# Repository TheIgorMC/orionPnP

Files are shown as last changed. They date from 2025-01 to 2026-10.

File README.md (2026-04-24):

# OrionPnP

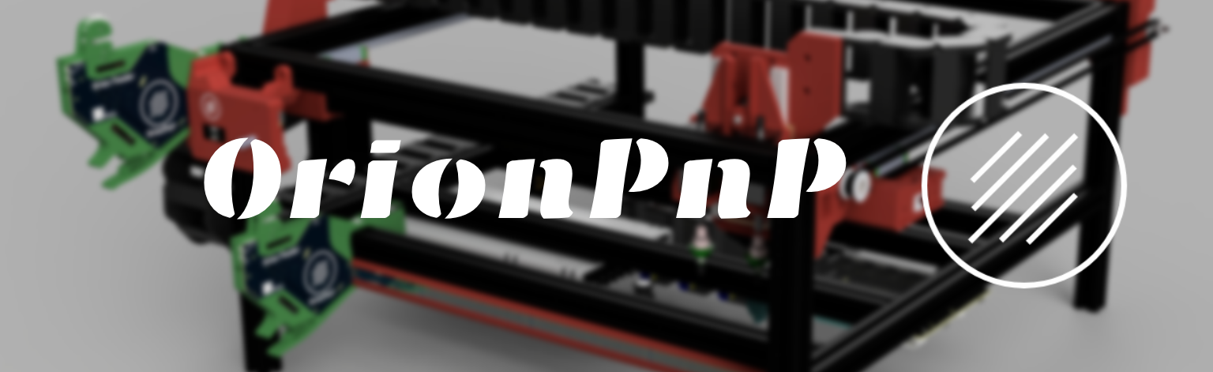
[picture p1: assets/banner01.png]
Banner for OrionPnP


> ⚠️ **DISCLAIMER:** OrionPnP is a prototype under active development. Testing and validation will begin after the first boards are fully assembled. Schematic, PCB, and BOM details may still change. Refer to the [Changelog](../../wiki/Changelog) and [Build Your Own](../../wiki/Build-Your-Own) pages for updates.

---

## What is OrionPnP?

**OrionPnP** is an open-source DIY Pick-and-Place (PnP) machine designed to integrate seamlessly with [OpenPnP](http://openpnp.org).  
The goal is to reliably place at least **0402 components**, while minimizing complexity and user effort — affordably and efficiently.

---

## Why This Project?

Most DIY PnP machines today are either:
- Too expensive
- Too unreliable
- Or both

**OrionPnP** takes a different path: _“minimum effort for maximum reliability.”_  
This means fewer parts, cleaner electronics, and a streamlined build process — optimized for consistent, precise assembly.

As of now, a complete OrionPnP machine (including electronics, mechanics, and **five assembled feeders**) is expected to cost around **800 EUR**, excluding printed parts. This makes it one of the most affordable fully-featured PnP options available.

---

## Why a Custom Mainboard?

Generic motion control boards (like 3D printer boards):
- Often include features irrelevant to PnP (e.g., CAN, multiple extruder support)
- Lack native support for vacuum sensing or multiple solenoids
- Are either too limited, too bloated, or too expensive

**OrionPnP introduces a purpose-built controller**:  
Just the features a PnP machine needs — nothing more.

---

## Key Features

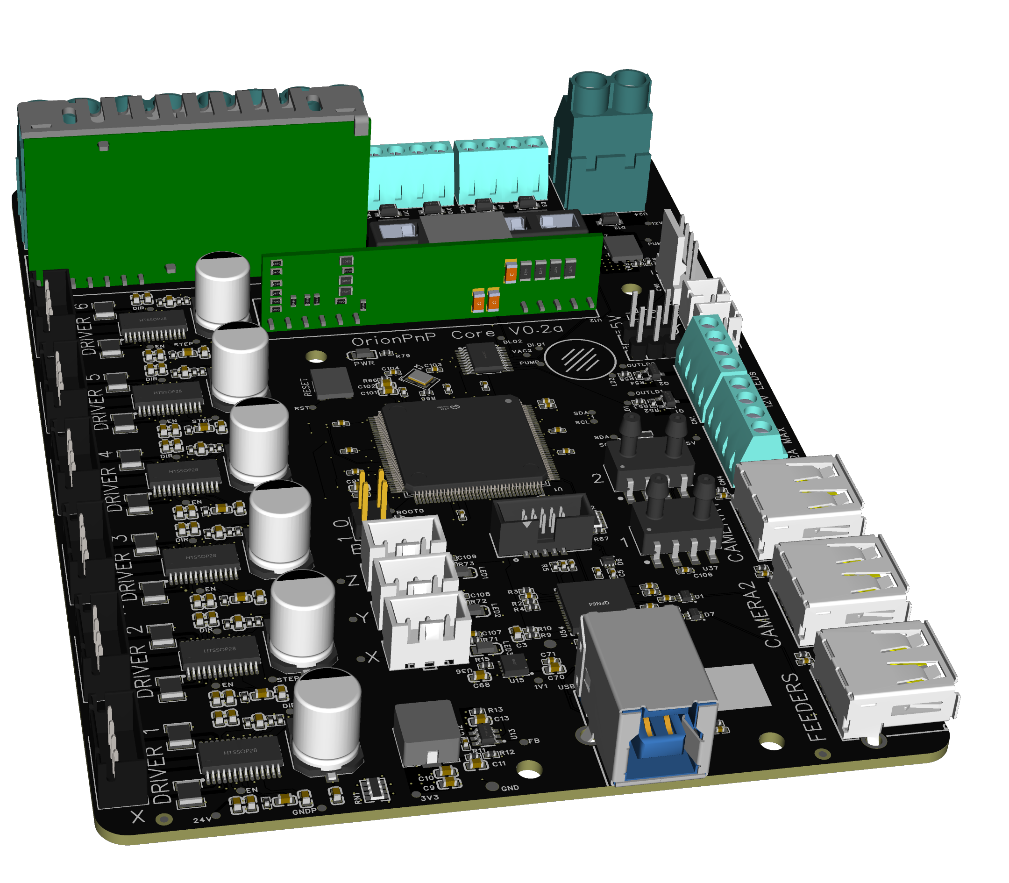
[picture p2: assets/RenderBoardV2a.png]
Render of the mainboard


### Motion & Control
- 6x **TMC2226 stepper drivers** with sensorless homing and UART control
- 4x **12V solenoid outputs** (flyback diodes pre-installed)
- 2x **12V LED ring outputs** for bottom and nozzle cameras
- 1x **12V vacuum pump output**, with back EMF protection

### Power & Expandability
- 24V input, 12V and 5V power rails with onboard buck converters
- 2x **2-pin fan headers** (selectable 5V or 12V)
- 1x **4-pin PC fan header** (12V only, non-PWM)
- Automotive-style fuses for 5V and 12V outputs

### Sensing
- 2x **I²C differential pressure sensors** (one per nozzle)
- Each sensor is isolated on its own I²C bus

### USB & Connectivity
- Integrated **USB 3.0 hub**
  - 3x downstream USB 2.0 ports
  - 1x direct stream to the MCU
  - USB 3.0 Type-B upstream port
  - One port is reserved for a **feeder expansion board**

---

## Software Approach

The mainboard runs a **customized Marlin 2.0 build**, chosen for:
- Mature GCODE support
- Existing OpenPnP compatibility
- Flexibility and ease of expansion

Current modifications include:
- Vacuum sensor hooks
- Solenoid and pump control
- LED and GPIO support for pick-and-place automation

More firmware integration details are covered in the [Software Overview](../../wiki/Software-Overview).

---

## Modular Feeder System

OrionPnP includes a distributed architecture of **smart feeders**, connected via RS485.  
Each feeder has its own microcontroller, optical sensors, and a command queue system.  
Feeders are assigned addresses automatically and can be hot-plugged or programmed via a dedicated interface.

See [Feeder Design](../../wiki/Feeder-Design) and [Command Reference](../../wiki/OrionProtocol) for full details.

---

## Host Interface

A **host controller** can manage feeders independently of the mainboard.  
It supports:
- Multi-line RS485 management
- Address assignment via screen + encoder
- OLED feedback and status display
- USB communication to OpenPnP

Typically based on the **STM32F072**, as described in the [Software Overview](../../wiki/Software-Overview).

---

## Tool Board

A dedicated **ToolBoard** (V0.1a) is mounted on the machine head and handles nozzle-level functions:
- Interfaces with solenoids, sensors, and LED lighting local to the toolhead
- Designed to reduce wiring runs back to the mainboard
- Hardware files (schematic, PCB, BOM, Gerbers, PnP CSV) are available in the [`ToolBoard/`](ToolBoard/) directory

---

## Reflow Oven

OrionPnP includes a companion **Reflow Oven** system for completing the board assembly workflow, built around a consumer oven (De'Longhi 3835A) to avoid expensive commercial controllers.

The system is developed in two phases:

### Phase 1 — Non-invasive monitoring (current)
- **RP2040 Pico firmware** (MicroPython): reads a MAX31855K SPI thermocouple amplifier every 500 ms and streams JSON lines over USB CDC serial
- **PC desktop application** (Dear PyGui, Python 3): connects to the Pico by USB VID/PID auto-detection, displays a live temperature graph, logs data to timestamped CSV, and runs a **"Follow Me"** guided reflow mode
- A **hardware-free MCU simulator** (`tools/simulate_mcu.py`) lets you develop and test the app without physical hardware, via virtual COM ports
- Targets low-temperature pastes (e.g. Sn42Bi58, ~138 °C peak)

### Phase 2 — Full hardware mod (future)
- Adds SSR control for closed-loop automated reflow (PC-bound PID or standalone Pico-resident PID)
- Supports standard and lead-free paste profiles (up to ~250 °C)

See [`Reflow-Oven/`](Reflow-Oven/) for firmware, app source, and the full phase specification.

---

## Assembly Manuals

Preliminary assembly manuals (PDF) for the first revision of the machine are available in the repo root:
- [Manual R01 V01a](Manual_R01_V01a.pdf)
- [Manual R01 V01b](Manual_R01_V01b.pdf)
- [Manual R01 V01c](Manual_R01_V01c.pdf)
- [Manual R01 V01d](Manual_R01_V01d.pdf) _(latest)_

---

## Project Scope

The core mainboard is in active prototyping.  
Feeder electronics and mechanics are now being finalized.  
CAD files, firmware, schematics, and wiring diagrams will all be published under open-source licenses.

See [Build Your Own](../../wiki/Build-Your-Own) for parts list, tools, and assembly tips.

---

## Project Status

- [x] CAD design of the frame and motion system
- [x] Production of electronic boards (Core, camera lights, toolhead boards...)
- [x] Assembly manual — first revision published (R01 V01d)
- [ ] First tests on electronics (ongoing...)
- [ ] Part printing (ongoing...)
- [x] Reflow oven Phase 1 app and firmware (in progress)

---

## Contributions Welcome

OrionPnP is a community-first project.  
Feel free to:
- Fork the repo
- Suggest improvements
- Report bugs or build issues

Please check in before large architectural changes — development is moving fast.

---

Stay tuned for updates on feeder programming, mechanical parts, and full assembly instructions.

---

## Support the Project

If you find OrionPnP useful or want to support its continued development, consider buying me a coffee:



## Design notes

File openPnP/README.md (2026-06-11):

# openPnP Configuration

This folder contains the openPnP configuration and supporting files for the Orion PnP machine.

## Files

| File | Description |
|---|---|
| `machine.xml` | Main openPnP machine configuration (axes, drivers, cameras, nozzles, feeders) |
| `packages.xml` | Component package definitions (footprints) |
| `parts.xml` | Parts library with component-to-package mappings |
| `vision-settings.xml` | Vision pipeline settings for part and fiducial detection |

## Scripts

Example scripts are provided in `scripts/Examples/` in both JavaScript and Python.

### JavaScript (`scripts/Examples/JavaScript/`)
- `Hello_World.js` — Basic scripting example
- `Move_Machine.js` — Machine movement control
- `Pipeline.js` — Vision pipeline scripting
- `Reset_Strip_Feeders.js` — Reset all strip feeders
- `QrCodeXout.js` — QR code utility
- `Call_Java.js` — Calling Java methods from scripts
- `Print_Scripting_Info.js` — Print available scripting objects
- `Utility.js` — General utility functions

### Python (`scripts/Examples/Python/`)
- `move_machine.py` — Machine movement control
- `print_nozzle_info.py` — Print nozzle status/info
- `print_hallo_openpnp.py` — Basic scripting example
- `call_java.py` — Calling Java methods from scripts
- `print_methods_vars.py` — Inspect available methods and variables
- `print_scripting_info.py` — Print available scripting objects
- `use_module.py` — Example of importing Python modules
- `utility.py` — General utility functions

The `scripts/Events/` folder is reserved for event-triggered scripts (e.g., job start/stop hooks).

### Utilities (`scripts/util/`)

| File | Description |
|---|---|
| `datasheet_to_feeder.py` | Reads a component datasheet PDF via the Gemini API and outputs an openPnP `BlindsFeeder` XML snippet with the extracted tape specs |
| `batch_parts_to_feeders.py` | Reads a CSV list of parts, groups by footprint then variation series, uses Gemini with web search to estimate tape specs and component size, and outputs bulk feeder XML + review report |
| `requirements.txt` | Python dependencies for the util scripts |
| `.env.example` | Template for the required `GEMINI_API_KEY` environment variable |

#### `datasheet_to_feeder.py` usage

```bash
# Install dependencies
pip install -r scripts/util/requirements.txt

# Copy and fill in your Gemini API key
cp scripts/util/.env.example .env

# Run against a datasheet PDF
python scripts/util/datasheet_to_feeder.py path/to/component.pdf \
    --part-id "C_0402_100NF" \
    --name "Feeder_0402_100nF" \
    --output feeder_0402.xml
```

The script uploads the PDF to the Gemini Files API, extracts the following fields, and writes a ready-to-import `<feeder>` XML element:

| Field extracted | openPnP attribute |
|---|---|
| Tape width | `tape-center-offset-mm` (via IEC 60286-3 lookup) |
| Feed pitch (A dimension) | `pocket-pitch` |
| Pocket size (A0/B0) | `pocket-size` |
| Sprocket pitch | `sprocket-pitch` |

The output XML can be pasted directly inside the `<feeders>` section of `machine.xml`.

#### `batch_parts_to_feeders.py` usage (CSV automation)

Use this when you already have a CSV with many part numbers (e.g. `scripts/util/exported.csv`).

```bash
# Install dependencies
pip install -r scripts/util/requirements.txt

# Run batch generation from a CSV export
python scripts/util/batch_parts_to_feeders.py scripts/util/exported.csv \
    --output scripts/util/feeders_generated.xml \
    --report scripts/util/feeders_generated_report.csv
```

What it does:

1. Reads `id`, `manufacturer_code`, and `smd_footprint` from the CSV.
2. Groups parts by `smd_footprint` first, then by inferred series/variation.
3. Calls search-enabled Gemini (`gemini-2.5-flash` + Google Search tool) per variation group to infer tape specs and component size.
4. Generates one `<feeder>` per CSV row with the inferred variation specs.
5. Writes a review CSV with footprint, variation, confidence, component dimensions, and datasheet URL.

The XML output contains a `<feeders>` root with comments showing footprint, variation, confidence, dimensions, and a datasheet source link for each block.

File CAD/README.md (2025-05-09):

# OrionPnP CAD & 3D Models

> This directory contains mechanical design files and 3D models used in the OrionPnP project. These are actively maintained and subject to change as hardware validation continues.

---

## Overview

The OrionPnP mechanical design is built around modularity and printability. It includes mounts, brackets, covers, and pogo-compatible parts used in the feeder system and frame.

The CAD models are designed with:
- **Fusion 360** as the main parametric environment
- STL exports for printing (3MF is gradually being added)
- A BOM covering all fasteners and support components, alongside the list of 3D printed components

---

## Contents

| File/Folder | Description |
|---|---|
| `/Feeders/` | Exported 3D files for feeders (M3F + STL) |
| `/OrionPnP/` | Exported 3D files for the machine (STL) |
| `OrionPnP_Main.f3d`| Main Fusion 360 assembly file (WIP) |
| `Hardware BOM.ods` | BOM spreadsheet (for components and 3D printed parts) |
| `TEMP_BOM.md` | Temporary Markdown file for quick BOM consultation |

---

## Notes

- Printed parts **should** be printable with smaller printers (e.g. Prusa Mini)
- STL exports are named by part function for easier identification
- Most parts are designed for **0.6mm nozzle, 0.2mm layer height**

---

## Bill of Materials

The [TEMP_BOM.md](./TEMP_BOM.md) file contains a full breakdown of:
- Printed parts
- Hardware (screws, nuts, spacers, etc.)
- Optional assembly tools and adhesives

---

## Printing Recommendations

- Material: **ABS/ASA** or **PETG** recommended for most parts
- Color: not relevant except for camera mounts (preferable black + white diffuser)
- Infill: 30–50% for structural components
- Supports: Only required for a few overhangs (noted per part)
- Use heat-set inserts for repeated fastening when indicated

---

## License

All CAD files are released under the same open-source license as the rest of the project. You are free to modify and redistribute them, but attribution is appreciated.

---

## Related Pages

- [Build Your Own](../../wiki/Build-Your-Own)
- [Feeder Design](../../wiki/Feeder-Design)
- [Hardware Overview](../../wiki/Hardware-Details)

---

Stay tuned as we finalize the mechanical design and publish full step-by-step assembly guides.

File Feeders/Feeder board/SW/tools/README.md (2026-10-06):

# RS485 command sender

Small PC-side tools for driving the feeder RS485 protocol directly from a
USB-RS485 adapter, instead of only through the debug port's text
commands. See `../PROTOCOL.md` for the frame format and full command
reference these implement against. Two front ends, same protocol logic
(`rs485_protocol.py`, shared by both):

- **`rs485_gui.py`** — Tkinter GUI. No separate install beyond pyserial
  (Tkinter ships with Python). Probably the one to start with.
- **`rs485_sender.py`** — command-line REPL, same commands as the GUI's
  "Custom command" panel, handy for scripting or an SSH session.

## Setup

```
pip install -r requirements.txt
```

## GUI

```
python rs485_gui.py
```

Pick a port and Connect. The baud is pre-filled from the newest firmware
folder's `RS485_BAUD` (read from `../<firmware>/src/main.cpp`); pick a
different firmware in the dropdown if the board runs an older build.
If the adapter needs the host to drive its direction pin manually (some
cheap adapters wire DE to RTS instead of auto-detecting direction), tick
"RTS controls TX (DE)" before connecting.

Every frame that arrives shows up in the log, decoded where the payload
shape is known (the once-a-second live refresh and the config read stay
out of it). Port, address and a few settings are remembered in
`~/.orionpnp_rs485_gui.json`.

**The feeder card** (left, always visible) is the part to watch during
first tests: the target **Address**, Ping / Identify / Refresh, a big red
**STOP** (also **Esc**), and live readouts that refresh once a second while
nothing else is running: link health, magnet (detected / none / too weak /
too strong), motor-driver fault, RS485 relay, wheel angle, 12V current
(approximate, from the factory calibration - the feeder's own `CALI` value
may differ) and the last move error. Below that, **Saved on this feeder**
shows component id, tape zero, pitch, tape width, peel time and peel rate,
read automatically the first time the feeder answers (and with **Read from
feeder**). Fields show "n/a" on firmware that doesn't have them. **STOP**
aborts the running sequence and broadcasts `CMD_STOP`; a feeder only hears
it between moves, because it does not listen to the bus while a motor runs.
The Identify button blinks the feeder's status LED white. v0.02b feeders
also flash their status LED green (blue in peel mode) whenever a frame is
addressed to them, so you can see which one is answering.

Tabs:

- **Bring-up.** A first-test checklist: connect, address, link, magnet and
  fault, tape width, pitch, zero, feed once, peel rate. Each row has its
  own button. Ticks come from what the feeder reports, so a feeder that
  was set up earlier shows up already done, and a red cross says why.
- **Feed & peel.** Pitch, Feed once and Back once (with a peel rate saved
  the peel follows, see below); and **Run cycle test**: N cycles of
  feed / peel in the order you pick, waiting for each ACK and logging how
  long each step took, with min/avg/max at the end. With a peel rate saved
  a feed already peels, so use "feed only" (the GUI warns if a cycle would
  peel twice). On v0.02 and earlier the host-side feed-then-peel cycle is
  the only way to pair them. Nothing overlaps: the feeder doesn't listen
  to the bus while a motor is running.
- **Peel calibration** (v0.02b). Four blocks. (1) The **peel rate** (ms of
  peel per mm of feed): save, read, turn off, and **-10/-5/-1/+1/+5/+10 %**
  fine-tune buttons that save immediately. (2) **Measure it**: **Feed (no
  peel)** moves the sprocket N mm with jog (which never touches the peel
  motor), **-250 ... +1000 ms** nudges peel until the cover tape is just
  taut, **Record measurement** adds a row (mm, ms, ms/mm); repeat a few
  times, **Use average**. Every nudge starts with a short soft-start ramp,
  so a few long nudges are closer to a real feed than many short ones; the
  measured number is a starting point. (3) **Verify**: **Feed (peel
  follows)**, **Back (peel reverses first)** (`CMD_FEED_BACK`), and N feeds
  in a row; slack after a feed means raise the rate, a pulled tape or a
  lifting pocket means lower it, then use the fine-tune buttons. (4) The
  older fixed-time peel (Peel once, save/read/run the saved time).
- **Jog & zero** (v0.02+). Buttons jog the sprocket by -4 ... +4 mm
  (4 mm = one tooth) or a custom distance, each reply shows the new raw
  angle, then **Set zero here** stores it as the tape zero. Jog does not
  move the peel motor.
- **Setup.** Address: **Scan** lists every unassigned feeder (nonce,
  component, tape width) so you can pick one and **Assign** it, or **Scan +
  assign** does both when exactly one answers and sets the address. Tape
  width (write/read). Status-LED brightness (v0.02b: saved on the feeder,
  presets 10-255). EEPROM: **I2C scan** shows what answers on the feeder's
  bus; if Get serial NACKs but the scan shows 0x50 and no 0x58, the chip is
  a plain AT24C02 with no factory serial: **Random** + **Program serial**
  writes one (read back to verify).
- **Packet builder.** Pick a command and fill in named fields (pitch in
  mm, peel time in ms, dropdowns for direction/motor/on-off). It shows
  what the command does, which reply to expect, gotchas, and a live
  byte-by-byte preview of the exact frame including the CRC. **Copy hex**
  puts the frame on the clipboard for use in another serial terminal. The
  payload hex box can be edited by hand to send something malformed.
  Broadcast-only commands (Discover/Assign) always go to addr 0x00.

## Production (TAP-Jig)

The **Production** tab runs the test-and-program routine for the jig
(pre-power checks, power-up, flash test firmware, switches, RESET, fault
line, LEDs, AS5600, serial number, motors, RS-485, EEPROM, flash production
firmware, final confirm) and logs a pass/fail record per unit. It talks to
the jig's 32u4 over its own USB port and runs avrdude for the ISP stages.
`tapjig_run.py` runs the same routine headless. Everything about it, the
jig line protocol, the test firmware and what is still open, is in
**`TAPJIG.md`**. The jig firmware does not exist yet; `sim_jig.py` stands in
for it.

## Trying it without hardware

`sim_feeder.py` (Linux/macOS only - it uses a pseudo-terminal) behaves
roughly like v0.02b firmware: boots unassigned, answers discovery and the
v0.02/v0.02b commands, and goes deaf while a "motor" runs.

```
python sim_feeder.py [--addr N] [--no-magnet]
```

It prints a device path such as `/dev/pts/5`; type that into the GUI's
Port box (or `rs485_sender.py --port`). It is not a faithful model of the
firmware, only enough to exercise the tools.

## CLI / REPL

```
python rs485_sender.py --list              # see available COM ports
python rs485_sender.py --port COM5         # open an interactive REPL
```

`--baud` defaults to the newest firmware's `RS485_BAUD`, same as the GUI.
If the USB-RS485 adapter needs the host to drive its direction pin
manually, add `--rts-tx` (same situation as the GUI's checkbox above).

Inside the REPL, `help` lists every command. There's a named command for
each protocol command (`ping`, `scan`, `getstatus`, `setpitch`, `peel`,
...) with friendly argument parsing, plus `raw <addr> <cmd> [hexbytes...]`
for sending anything else — custom payloads, malformed frames, whatever
you want to throw at a feeder that the named commands don't cover.

Typical first session on a bus with one feeder:

```
RS485> scan
  broadcasting CMD_DISCOVER, listening for 0.50s...
  RX: addr=0x00 cmd=CMD_DISCOVER_HERE payload=... | nonce=0x1A2B componentId=UNSET tapeWidth=8mm
RS485> assign 0x1A2B 5
  RX: addr=0x05 cmd=CMD_ACK payload=05 | ...
RS485> ping 5
  RX: addr=0x05 cmd=CMD_PONG payload=(empty) |
RS485> getstatus 5
  RX: addr=0x05 cmd=CMD_STATUS_INFO payload=... | angle=12.3deg (raw=140) magnet=OK (MD=1 ML=0 MH=0) fault=0 lastMoveErr=ERR_NONE iMonRaw=0 relay=disconnected
```

Addresses, command codes, and `raw`'s hex bytes all accept either decimal
or `0x..` hex. Bus address `0x00` is broadcast.

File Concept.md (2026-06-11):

### Machine architecture

The **OrionPnP** machine is comprised of:
- The machine itself with:
  - One **mainboard** (ATmega2560 based board) that controls the motors and ligths/pumps/solenoids. Driven via GCODE commands over COM.
  - Two **USB cameras**, one on the picking head, one fixed on the build plate. Each has its own independent USB cable.
  - One **Feeder host**, with at least two RS485 buses. One is for the feeders connected to the machine, one is reserved for a programming slot to program new feeders. Communicates via GCODES over COM.
  - One **feeder rail**, a simple PCB strip to connect feeders to the machine. It carries 12V, GND, A and B from the RS485 bus.
- A computer or SBC with [OpenPnP](https://openpnp.org/) installed and decent processing power.
- Feeders of various types for different tape widths (8, 12, 16...). Each feeder has 2 motors connected to a driver to advance the tape and peel the protective film.

The main concept to understand is that the heavy processing is made on the PC/SBC and the other boards need decresing levels of elaboration done. The hierarchy is like this:

- PC/SBC running OpenPnP
  - Feeder host board
    - Feeders
  - Mainboard of the OrionPnP

The method for adding the feeders to the machine is the one in this procedure:
1. Snap a feeder on the programmer area of the host.
2. Set with the simple menu or via custom PC commands the informations on the carried component (tape width, pitch of parts, part ID). These are used by the feeder to know which parts it is feeding and how to properly drive the motors.
3. Unlatch the feeder from the programmer area of the host.
4. Put the feeder on any empty section of the rail.
5. Some sort of *polling command* runs periodically and detects the new feeder.
6. A time is waited to see if more feeders are connected to either the rail OR the programmer (10s?).
7. After the delay passed, the head moves on the feeder section and a custom script runs on the PC/SBC.

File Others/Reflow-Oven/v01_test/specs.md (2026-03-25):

# Reflow Oven — v01 Test Specification

## Overview

The OrionPnP handles component placement, but a reflow oven is required to complete the board assembly workflow. Commercial solutions are expensive and importing purpose-built controllers (e.g. Controleo3) adds further cost and complexity. The chosen approach is a fully DIY system built around a consumer oven, implemented in two progressive phases.

---

## Hardware Base

| Parameter | Value |
|---|---|
| Oven model | De Longhi 3835A |
| Internal volume | 21 L |
| Rated power | 1800 W |
| Future insulation | Reflective shielding (TBD, Phase 2) |

The 1800 W power rating is acceptable for low-temp pastes. For lead-free profiles with faster ramp rates, additional insulation may be required.

---

## Build Phases

### Phase 1 — Non-invasive monitoring (current focus)

**Goal:** Characterise the oven's thermal behaviour and enable guided manual reflow without any permanent hardware modification.

**Hardware:**
- K-type thermocouple (routed through the oven door seal or a small grommet)
- MAX31855K SPI thermocouple amplifier breakout
- **RP2040 Pico** connected to MAX31855K via SPI

**Firmware:**
- **MicroPython** on the RP2040 Pico
- Samples MAX31855K every 500 ms, streams JSON lines over USB CDC serial
- Output format: `{"t":<uptime_ms>,"tc":<float>,"ref":<float>,"fault":<0|1>}`
- Accepts incoming JSON commands (stubbed for Phase 2 SSR control)

**Software:**
- **Dear PyGui** native desktop application (GPU-rendered, Windows/macOS/Linux)
- Reads temperature over USB serial from the Pico (auto-detects by USB VID/PID 0x2E8A)
- Logs time/temperature data to timestamped CSV
- Implements calibration procedure (see below)
- Implements "Follow Me" guided reflow mode (see below)

**Target paste types:** Low-temperature solder pastes (e.g. Sn42Bi58, ~138 °C peak)

---

### Phase 2 — Full hardware mod (future)

**Goal:** Fully automated reflow with closed-loop control, suitable for standard and lead-free pastes.

Phase 2 supports two independent sub-modes that share the same hardware additions. The UI introduced in Phase 1 remains unchanged; a new **SSR Control** panel is added to the PC app for PC-bound mode.

---

#### Phase 2a — PC-bound mode

The host PC runs the PID control loop. The Pico firmware gains GPIO outputs for SSR1/SSR2 and accepts `{"cmd":"set_ssr","ssr1":0,"ssr2":1}` commands already stubbed in Phase 1 firmware.

- PID executes on the PC; USB round-trip latency (~10–50 ms) is negligible for thermal systems with time constants of tens of seconds.
- The Dear PyGui app gains a **SSR Control** panel: target profile selector, Start/Stop, live PID tuning (Kp/Ki/Kd).
- Logging and calibration workflows from Phase 1 are reused unchanged.

#### Phase 2b — Standalone mode

The PID loop and profile runner move onto the Pico. A display module (hardware TBD) replaces the PC for in-field use.

- Pico firmware extended: profile storage (LittleFS or SD), PID controller, display driver.
- The PC app remains available for monitoring, log download, and profile upload over USB.
- Profile and calibration file formats are identical to Phase 1 (JSON) for full compatibility.

---

**Shared hardware additions (both sub-modes):**
- 2× SSR (Solid State Relay): one for the oven heating elements, one for the convection fan
- At least one additional thermocouple (consider two: air + board surface)
- Replacement thermal fuse rated for cycling use
- Phase 2b only: embedded display module (hardware TBD during Phase 2 design)

**Target paste types:** Lead-free (Sn63Pb37 and SAC305, up to ~250 °C peak)

---

## Phase 1 — Software Specification

### Calibration Procedure

The purpose of calibration is to characterise the oven's thermal response curve — specifically how temperature evolves over time when running at **maximum power**, as a function of the temperature setpoint dialled in.

**Approach:**
- Run the oven at **max power only** (no partial-power sweeps).
- Set several discrete temperature targets across the useful range and record how the measured temperature varies over time for each.
- The script logs the full time/temperature curve for each setpoint, capturing ramp rate, overshoot, and settling behaviour.

**Spatial variation (optional):**
- The procedure can be repeated **2–3 times** with the thermocouple placed in different positions inside the oven cavity (e.g. centre, front corner, near elements) to map thermal uniformity.
- This is particularly relevant for board placement decisions in Follow Me mode.

**Empirical nature:**
- The actual curve shape is unknown until tested on the real oven. The calibration run will drive the design of the Follow Me prediction model — no assumptions are made upfront about linearity or lag characteristics.

**Procedure steps:**
1. Start with oven cold (ambient temperature).
2. Set oven dial to max power.
3. Dial in the first temperature target; script begins logging temperature vs. time.
4. Record until the oven reaches steady state or overshoots and stabilises.
5. Let the oven cool down, then repeat from step 2 for the next temperature target.
6. Optionally repeat the full sequence with the thermocouple repositioned.
7. Script post-processes the logged curves to extract ramp rate (°C/s) and any overshoot per target.

**Output:** A calibration file (JSON or CSV) per thermocouple position, containing the time/temperature curves and derived ramp characteristics, consumed by the Follow Me mode.

---

### Reflow Profiles

A profile defines the target temperature curve for a reflow cycle. Each profile is a sequence of named stages.

**Profile format (example — Sn42Bi58 low-temp paste):**

| Stage | Target temp (°C) | Ramp rate (°C/s) | Dwell time (s) |
|---|---|---|---|
| Preheat | 90 | ~1.0 | 60 |
| Soak | 130 | ~0.5 | 90 |
| Reflow | 165 | ~1.5 | 30 |
| Cooling | ambient | natural | — |

Profiles are stored as simple JSON files so they can be created and edited without modifying the script.

**Fields per stage:**
```json
{
  "name": "Soak",
  "target_temp": 130,
  "max_ramp_rate": 0.5,
  "dwell_seconds": 90
}
```

---

### Follow Me Mode

The script guides the user through a reflow profile by issuing real-time instructions based on live temperature readings and the calibration delta table.

**Behaviour:**
- Displays a live temperature plot (time on X axis, °C on Y axis) with the target profile overlaid.
- Calculates how far ahead of the current temperature the user needs to act (based on the calibration delta) to hit the next stage on time.
- Issues a prompt when the user must change the oven dial setting, including:
  - Which direction to turn (up/down)
  - How many notches/steps (if the dial positions are enumerated during calibration)
- Alerts if the actual temperature curve deviates outside a configurable tolerance band around the target profile.
- Logs the full run (timestamp, setpoint stage, measured temp, any user actions) to a CSV file for post-run review.

**UI — Dear PyGui desktop application:**
- Dark-themed native window (Catppuccin Mocha palette), 1280 × 800 minimum
- Sidebar navigation: Dashboard | Calibration | Follow Me | Profiles | Logs
- **Dashboard:** live temperature readout, connection panel, 60 s mini-plot
- **Calibration wizard:** step-by-step guided recording with live plot
- **Follow Me:** full-width live plot with profile overlay, action instruction card, alert card
- **Profile Manager:** list and inspect JSON profiles
- Live `TempPlotWidget` shared across views: actual temp (blue), target profile (amber dashed), ±tolerance band (red)

---

## Open Questions / TODOs

- [x] ~~Identify MCU to use for Phase 1~~ → **RP2040 Pico + MicroPython**
- [x] ~~Decide on Python UI approach~~ → **Dear PyGui native desktop app**
- [x] ~~Define profile file naming and storage convention~~ → `profiles/<name>.json`, calibrations in `calibrations/<name>.json`
- [x] ~~Define tolerance band for Follow Me deviation alerts~~ → **±5 °C default** (configurable per session)
- [ ] Confirm thermocouple routing — door seal gap vs. drilled grommet
- [ ] Enumerate oven dial positions (how many discrete settings, approximate power per step) — drives "turn N notches" instruction in Follow Me
- [ ] Test MAX31855K noise at 1800 W load (check for EMI on SPI lines)
- [ ] Phase 2: identify suitable SSR models for 230 V / 1800 W load (Crydom D2425/D4825 or equivalent)
- [ ] Phase 2b: select display module (ILI9341 320×240 TFT vs. SSD1306 128×64 OLED vs. Nextion)

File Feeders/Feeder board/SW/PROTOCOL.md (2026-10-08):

# Feeder RS485 Protocol (beta1 / v0.01a / v0.02 / v0.02b) — current state

This is the canonical spec for the frame protocol implemented in
`beta1/src/main.cpp` and `v0.01a/src/main.cpp` (identical protocol
surface — v0.01a only disables two bench-only auto-run test aids, see
`v0.01a/project.md`), kept separate from `alpha01`/`alpha02`/`alpha03`/
`beta1`/`v0.01a`'s `project.md` files so it doesn't drift out of sync
across five copies. Still **not Modbus** — see `alpha01/project.md`'s
Modbus feasibility section for why that's still an open decision; this
is what's actually implemented today.

- Command rows are tagged with the firmware that introduced them.
  `v0.02` adds `0x35`–`0x39`, `v0.02b` adds `0x3A`–`0x3D`; both otherwise
  keep the beta1/v0.01a surface. The PC tools (`tools/`) implement all of it.
- `alpha03` implements everything here except `CMD_STATUS_INFO`'s last
  three payload bytes (`iMonRaw`/`relayEngaged` - alpha03 has no I_MON or
  relay), and `invertMotorA` defaults to `false` there instead of `true`.
- `alpha02` additionally lacks `CMD_GET_SERIAL`, and its
  `CMD_DISCOVER_HERE`/`CMD_GET_HW_INFO`/`CMD_SET_HW_INFO` read/write
  `FeederHardwareInfo` from the ATmega's internal EEPROM, not an AT24CS02
  (alpha02 doesn't have one).
- `alpha01` implements a smaller subset still (everything up to and
  including `CMD_SET_EXT_LED`, no hardware info/status/stop/identify/
  serial) plus its own `RS485ECHO` debug-only test mode.
- See `alpha01/project.md`.

## Physical layer

- RS485 half-duplex, MAX1487 transceiver, combined RE#/DE direction
  control on one MCU pin (`PIN_RS485_RE`).
- 9600 baud — both feeder UARTs (RS485 + local debug) run off the
  ATmega328PB's internal 8MHz RC oscillator, which isn't accurate enough
  for standard higher bauds. Revisit if a crystal is added in a future
  hardware revision.

## Frame format

```
[0xAA][ADDR][CMD][LEN][PAYLOAD...][CRC8]
```

| Field | Size | Notes |
|---|---|---|
| Start | 1 B | fixed `0xAA` |
| ADDR | 1 B | `0x00` = broadcast (also "still unassigned"); `1`–`247` = unicast bus address |
| CMD | 1 B | command/reply code, see table below |
| LEN | 1 B | payload length in bytes (0–16) |
| PAYLOAD | LEN B | command-specific |
| CRC8 | 1 B | poly `0x07`, computed over `ADDR..PAYLOAD` (not the start byte) |

A feeder's own address (or `0x00` while unassigned) always tags frames it
sends. Unknown commands are silently ignored; a CRC mismatch silently
drops the frame (no retry/NACK — the sender's own timeout is the recovery
mechanism, matching a simple RTU-style bus).

## Addressing / discovery

Bus address is **RAM-only and disposable** — no EEPROM persistence, no
dedicated programming bus (dropped from the project; see
`alpha01/project.md` "Addressing scheme, v2" for the full reasoning).
Every boot starts at `ADDR_UNASSIGNED` (`0x00`) and re-earns an address
each time:

1. Host broadcasts `CMD_DISCOVER`.
2. Every still-unassigned feeder waits a random jitter delay (up to
   `DISCOVERY_JITTER_MAX_MS`, 200ms) then replies `CMD_DISCOVER_HERE` with
   its session nonce, its persisted component id, and (as of this
   revision) its tape width — so a host learns most of what it needs
   about a feeder in one round-trip, without separate queries for the
   common case.
3. Host picks a free address and broadcasts `CMD_ASSIGN_ADDR` with that
   nonce; only the matching feeder adopts the address.

## Command reference

`CMD_ACK` = `0x82`, `CMD_NACK` = `0x83` (payload `[errCode]` where noted —
see **Error codes** below; otherwise empty).

| Command | Code | Payload → | Reply | Notes |
|---|---|---|---|---|
| `CMD_PING` | `0x01` | — | `CMD_PONG` (`0x81`) | liveness check |
| `CMD_DISCOVER` | `0x10` | broadcast, — | `CMD_DISCOVER_HERE` (`0x90`): `[nonceHi,nonceLo,componentIdHi,componentIdLo,tapeWidthMm]` + **v0.02b**: `[lastAddr,posXHi,posXLo]` | only unassigned feeders react |
| `CMD_ASSIGN_ADDR` | `0x11` | broadcast, `[nonceHi,nonceLo,newAddr]` | `CMD_ACK` under the new address | only the matching nonce adopts it |
| `CMD_GET_COMPONENT` | `0x20` | — | `CMD_COMPONENT_INFO` (`0xA0`): `[idHi,idLo,zeroHi,zeroLo,feedHalfTeeth]` | |
| `CMD_SET_COMPONENT` | `0x21` | `[idHi,idLo]` | `CMD_ACK` | resets tape zero + pitch if the id actually changed |
| `CMD_SET_FEED_CONFIG` | `0x22` | `[zeroHi,zeroLo,feedHalfTeeth]` | `CMD_ACK` | low-level, sets both fields directly |
| `CMD_RESET_CONFIG` | `0x23` | — | `CMD_ACK` | clears tape zero + pitch only, keeps component id |
| `CMD_ZERO_HERE` | `0x24` | — | `CMD_ACK` | captures current position as tape zero |
| `CMD_SET_PITCH_MM` | `0x25` | `[mm]` (1 B) | `CMD_ACK`/`CMD_NACK` | auto-translated to `feedHalfTeeth` |
| `CMD_FEED_NEXT` | `0x26` | — | `CMD_ACK` / `CMD_NACK[errCode]` | advance by configured pitch |
| `CMD_SET_EXT_LED` | `0x27` | `[state]` (0/nonzero) | `CMD_ACK`/`CMD_NACK` | standard LED, plain on/off. alpha01/02: D13/PB5 (shares the ISP header's SCK line). alpha03: A3/PC3 (own pin, no ISP conflict) |
| `CMD_SET_INVERT_DIR` | `0x28` | `[motor(0=A,1=B), state(0/1)]` | `CMD_ACK`/`CMD_NACK` | RAM-only, resets on reboot |
| `CMD_GET_HW_INFO` | `0x29` | — | `CMD_HW_INFO` (`0xA1`): `[tapeWidthMm]` | `0xFF` = unset |
| `CMD_SET_HW_INFO` | `0x2A` | `[tapeWidthMm]` | `CMD_ACK`/`CMD_NACK` | assembly/bench-time only, validated against EIA-481 widths, no reset command | **v0.02b**: production firmware answers `CMD_NACK [ERR_LOCKED]`; only the `TAPJIG_TEST` build writes (the AT24 is write protected).
| `CMD_GET_STATUS` | `0x30` | — | `CMD_STATUS_INFO` (`0xA2`): `[angleRawHi,angleRawLo,as5600Status,faultActive,lastMoveErr,iMonRawHi,iMonRawLo,relayEngaged]` | live telemetry; last 3 bytes **beta1 only** (alpha02/03 send the first 5) |
| `CMD_STOP` | `0x31` | — | `CMD_ACK` | immediate brake, both motors |
| `CMD_IDENTIFY` | `0x32` | `[blinkCount]` (0 ⇒ default 3) | `CMD_ACK` (after blinking) | white LED flashes, distinct from the magnet-status green/red |
| `CMD_GET_SERIAL` | `0x33` | **alpha03+** — — | `CMD_SERIAL_INFO` (`0xA3`): 16 bytes | AT24CS02 factory-programmed 128-bit serial number; `CMD_NACK` if the chip didn't respond |
| `CMD_PEEL` | `0x34` | **v0.01a+** — `[dir(0=fwd,1=rev), duration×10ms (1–255)]`; **v0.02+** also `[dir]` alone | `CMD_ACK` (after the run) / `CMD_NACK` | runs the peel motor alone (open loop) to tension the cover tape; stops early on a DRV8833 fault. With `[dir]` alone (v0.02) it runs this feeder's calibrated time, `CMD_NACK [ERR_NOT_READY]` if none is saved |
| `CMD_SET_PEEL_TIME` | `0x35` | **v0.02+** — `[msHi,msLo]` (10–5000) | `CMD_ACK` (echo) / `CMD_NACK [ERR_BAD_PARAM]` | saves this feeder's peel time in the ATmega's internal EEPROM. Per feeder, independent of the loaded component: survives `CMD_SET_COMPONENT` and `CMD_RESET_CONFIG` |
| `CMD_GET_PEEL_TIME` | `0x36` | **v0.02+** — — | `CMD_PEEL_TIME_INFO` (`0xA4`): `[msHi,msLo]` | `0xFFFF` = not calibrated |
| `CMD_JOG` | `0x37` | **v0.02+** — `[hi,lo]` signed, 0.1 mm units (±1600) | `CMD_ACK [angleRawHi,angleRawLo]` / `CMD_NACK [errCode]` | relative move of the sprocket (negative = backwards), same closed-loop move/stall/timeout handling as `CMD_FEED_NEXT`. The ACK carries the new raw angle. Use to seat a hole, then `CMD_ZERO_HERE`. Blocks like a feed |
| `CMD_I2C_SCAN` | `0x38` | **v0.02+** — — | `CMD_I2C_SCAN_INFO` (`0xA5`): responding 7-bit addresses, up to 16 | diagnoses the AT24: `0x36` AS5600, `0x50`–`0x57` EEPROM, `0x58`–`0x5F` AT24CS02 serial page |
| `CMD_SET_SERIAL` | `0x39` | **v0.02+** — 16 serial bytes | `CMD_ACK` / `CMD_NACK [ERR_LOCKED \| ERR_I2C]` | programs a serial into the normal EEPROM (offset `0x10`, with CRC) and reads it back. Only for a plain AT24C02; `ERR_LOCKED` if an AT24CS02 factory serial exists |
| `CMD_SET_LED_BRIGHTNESS` | `0x3A` | **v0.02b+** — `[level]` (1–255) | `CMD_ACK` (echo) / `CMD_NACK [ERR_BAD_PARAM]` | status RGB brightness, saved in internal EEPROM (default 40). Applied immediately |
| `CMD_SET_PEEL_RATE` | `0x3B` | **v0.02b+** — `[hi,lo]` in 0.1 ms-of-peel per mm of sprocket travel (5–5000; `0` = off) | `CMD_ACK` (echo) / `CMD_NACK [ERR_BAD_PARAM]` | couples peel to feed. A forward feed (`CMD_FEED_NEXT`, SW1) peels forward for `rate × mm`, starting once the sprocket has moved 2 mm (overlapping the rest of a longer feed), or after the feed if it is 2 mm or less. A backward seat (`SNAP`, post-homing) peels in **reverse first**, by the same `rate × mm`, then moves. Not applied to `CMD_JOG`, fast feed, `MOVEMM`/`GOMM`. `CMD_FEED_NEXT`'s reply now arrives after the peel too (peel is capped at 5 s). Per feeder, internal EEPROM, independent of the component |
| `CMD_GET_PEEL_RATE` | `0x3C` | **v0.02b+** — — | `CMD_PEEL_RATE_INFO` (`0xA6`): `[hi,lo]` | `0xFFFF` = unset (no coupling) |
| `CMD_FEED_BACK` | `0x3D` | **v0.02b+** — — | `CMD_ACK` / `CMD_NACK [errCode]` | the mirror of `CMD_FEED_NEXT`: back up by the configured pitch; with a peel rate set, peel in **reverse first**, then move. `ERR_NOT_READY` if no pitch is set. Blocks for the move plus the peel |
| `CMD_SET_POSITION` | `0x3E` | **v0.02b+** — `[xHi,xLo]` opaque slot position (suggested unit 0.1 mm along X; `0xFFFF` = clear) | `CMD_ACK` (echo) | persisted in the internal EEPROM; announced in `CMD_DISCOVER_HERE`. A cheap layout check for the host, not proof of identity |
| `CMD_GET_POSITION` | `0x3F` | **v0.02b+** — — | `CMD_POSITION_INFO` (`0xA7`): `[xHi,xLo,lastAddr]` | `0xFFFF` = unset, `lastAddr` 0 = never assigned |
| `CMD_T_INPUTS` | `0x40` | **test build only** — — | `CMD_T_INPUTS_INFO` (`0xB0`): `[flags,imonHi,imonLo,v5Hi,v5Lo]` | flags: b0 SW1 down, b1 SW2 down, b2 DRV nFAULT low, b3 relay coil on, b4 magnet detected. TAP-Jig only (`-DTAPJIG_TEST`); the production build ignores it |
| `CMD_T_UPTIME` | `0x41` | **test build only** — — | `0xB1`: `[ms x4 big-endian, MCUSR at boot]` | bit 1 of MCUSR = external reset |
| `CMD_T_RGB` | `0x42` | **test build only** — `[r,g,b]` (all 0 = release) | `CMD_ACK` | holds the status RGB |
| `CMD_T_MOTOR` | `0x43` | **test build only** — `[motor 0=A/1=B, dir, ms/10]` | `CMD_ACK [faultSeen]` | open-loop full-duty drive with soft start; stops on a DRV fault |

## Error codes

Returned in a `CMD_NACK` payload wherever a command's failure has a
specific, useful cause (currently `CMD_FEED_NEXT`; `CMD_GET_STATUS`'s
`lastMoveErr` field reports the same codes for the most recent move,
whether or not it was triggered by the command currently being handled —
e.g. a local button jog). `0x00` is the only success value.

| Code | Name | Meaning |
|---|---|---|
| `0x00` | `ERR_NONE` | success |
| `0x01` | `ERR_FAULT` | DRV8833 `nFAULT` asserted during the move |
| `0x02` | `ERR_MAGNET_LOST` | AS5600 stopped reporting a detected magnet mid-move |
| `0x03` | `ERR_STALL` | no encoder motion for `STALL_TIMEOUT_MS` |
| `0x04` | `ERR_TIMEOUT` | move exceeded its timeout without reaching target |
| `0x05` | `ERR_BAD_PARAM` | malformed/out-of-range command payload |
| `0x06` | `ERR_NOT_READY` | e.g. `CMD_FEED_NEXT` requested before pitch/zero calibrated; `CMD_PEEL [dir]` with no saved peel time |
| `0x07` | `ERR_I2C` | **v0.02+** — AT24 EEPROM didn't answer, or a write didn't read back identically (also `CMD_GET_SERIAL` with no serial available) |
| `0x08` | `ERR_LOCKED` | **v0.02+** — `CMD_SET_SERIAL` refused: an AT24CS02 factory serial exists |

## Hardware identity vs. per-component config

Two separate persisted structures, on purpose — see `alpha02/project.md`
for the full reasoning:

- **`FeederConfig`** (component id, tape zero, feed pitch) — reset
  whenever `componentId` changes or on an explicit `CMD_RESET_CONFIG`.
  This is "what's currently loaded." Always the ATmega's internal EEPROM,
  on every firmware version.
- **`FeederHardwareInfo`** (tape width) — set once at
  assembly/bench-test time, never reset by anything else. This is "what
  this physical unit is," fixed by its mechanical build (tape guide/rail
  width), identical for every reel ever loaded into it. It does not feed
  into any of the firmware's own motion math — sprocket hole pitch is a
  fixed 4mm regardless of tape width (EIA-481) — its value is purely
  informational, for a host to validate reel compatibility and for fleet/
  inventory management. Included in the `CMD_DISCOVER_HERE` reply so a
  host learns it immediately without a separate query in the common case.
  Storage location differs by version: alpha01/02 keep it in the ATmega's
  internal EEPROM (same as `FeederConfig`, different address); **alpha03
  moves it onto the AT24CS02's EEPROM** (byte offset `0x00`), so it
  survives even a full chip-erase/reflash of the ATmega, not just a
  component change — see `alpha03/project.md`.

### AT24C02 vs AT24CS02 (v0.02)

The two parts look identical on the bus except for the `-CS` serial page.
A plain **AT24C02** answers at `0x50` (so tape width reads and writes fine)
but nothing ever answers at `0x58`, so `CMD_GET_SERIAL` can only fail.
v0.02 handles both: the factory serial wins if `0x58` answers, otherwise a
serial programmed with `CMD_SET_SERIAL` is read from EEPROM offset `0x10`
(16 bytes + a CRC8 byte). `CMD_I2C_SCAN` tells the two apart. EEPROM
writes are also split on the part's 8-byte page boundaries (a longer write
wraps within the page and corrupts it), which matters for the 17-byte
serial block.

### AT24CS02 (alpha03 only)

I2C EEPROM + factory-programmed, read-only 128-bit unique serial number,
on the same I2C bus as the AS5600 (`SDA`/`SCL`, different address, no new
pins). Two I2C device-select addresses per the datasheet — not two memory
regions within one address:

- `0x50` — general-purpose EEPROM (read/write). `FeederHardwareInfo` lives
  at byte offset `0x00` here.
- `0x58` — identification page (read-only, factory-programmed). The
  128-bit serial number is read from byte offset `0x00` of this address,
  16 bytes, exposed via `CMD_GET_SERIAL`.

Not present on any V0.2a board built so far — `alpha03` is the first
firmware to expect it, ahead of the beta1 schematic actually adding it.
Every access is written to degrade gracefully (checked
`endTransmission`/`requestFrom`, same defensive pattern as the AS5600
code) rather than hang if the chip isn't populated: `CMD_GET_HW_INFO`
reports `tapeWidthMm = 0xFF` (unset) and `CMD_GET_SERIAL` replies
`CMD_NACK` instead of crashing or blocking. **None of this has been
validated against real AT24CS02 silicon** — the address assumptions,
the identification-page layout, and the fixed 5ms write-cycle delay (no
ack-polling implemented) are all from the datasheet, not from a working
board.

## Power sequencing (beta1 only)

Not present on any board built so far — beta1 is the first firmware to
expect this hardware, ahead of the schematic actually adding it.

- **`PIN_I_MON` (A6/PE2)** — analog, the IMON output of a TPS26600 eFuse
  on the 12V rail (RIMON=309kΩ, 1%), voltage proportional to load
  current, linear through the origin: ~4.07V at the 200mA design max
  load. Read with the default AVCC reference. `iMonRaw` (raw ADC) goes
  out over `CMD_STATUS_INFO`; firmware also exposes a converted
  `readIMonMilliamps()` (used by the `IMON`/`STATUS` debug commands),
  scaled through a hand-calibratable `AnalogCalibration` point (falls back
  to the 4.07V/200mA factory-calculated default until calibrated) — see
  "Hand calibration" below. `EN`/`FLT#` are not wired to the MCU — the MCU
  only runs once the eFuse is already on, so there's no fault state where
  firmware could still be reading a pin to report it.
- **`PIN_5V_READY` (A2/PC2) + `PIN_485_RELAY` (A7/PE3)** — a 4.7k
  (rail)/1k (GND) divider on the 5V rail gates a MOSFET-driven relay that physically
  connects/disconnects this feeder's RS485 lines from the shared bus.
  The relay stays disconnected at reset and only engages once the rail
  has read stable for 500ms (`RELAY_READY_STABLE_MS`), so a feeder that's
  still mid-power-up can't disturb a bus already in use. `relayEngaged`
  is reported in `CMD_STATUS_INFO`; there's no bus command to force it
  (deliberate — if the relay's open, a bus command couldn't reach the
  feeder to force it anyway; use the `RELAY ON`/`OFF` debug-port override
  for bench testing instead).

  **Reference gotcha:** `PIN_5V_READY` is read against the ATmega's
  internal 1.1V bandgap reference, not the default AVCC — the divider
  taps the same 5V rail that AVCC normally *is*, so an AVCC-referenced
  read would report a fixed ratio regardless of the rail's actual value
  and could never detect "still ramping." The internal reference fixes
  detection; the 4.7k/1k ratio (~0.88V, ~816/1023 counts against the 1.1V
  reference at a healthy 5V rail) was chosen so it only clips above
  ~6.27V, comfortably clear of a 5V rail's normal tolerance, while using
  ~80% of the ADC's range — roughly 2x the resolution of a 10k/1k
  alternative. See `beta1/project.md`, "5V rail reading: a reference
  gotcha," for the full comparison. `read5vRailMillivolts()` converts the
  raw reading to mV the same hand-calibratable way as IMON above, and
  `estimateI5vMilliamps()` derives a rough 5V-rail current estimate from
  IMON + a 12V-nominal power balance — debug convenience only, not a real
  measurement (see "Hand calibration" below and the function's comment for
  what it ignores).

**Hand calibration:** IMON and 5V_READY are both stored as a single
`(raw ADC, real-world value)` point (`AnalogCalibration`, in the ATmega's
internal EEPROM, independent of `FeederConfig`/`FeederHardwareInfo` — a
component change or `RESETCFG` never touches it), assumed linear through
the origin. Debug-port-only (bench/jig use, like `RELAY`/`IMON`/`5VSTATUS`
— no bus opcodes, since there'd be no bus link to reach a feeder that
still needs calibrating): `CALI <mA>` captures the current `PIN_I_MON` raw
reading against a real ammeter reading right now; `CALV <V>` does the same
for `PIN_5V_READY` against a real multimeter reading; `CALSTATUS` prints
both stored points; `CALRESET` reverts to the factory-calculated defaults.

## Motor direction default (beta1 only)

`invertMotorA` defaults to `true` in beta1 (`false` in alpha02/03) — the
final board's DRV8833 OUT1/OUT2 (motor-output side) are swapped relative
to the bench units this control loop was originally tuned against. Still
runtime-overridable (`INVERTA`, `CMD_SET_INVERT_DIR`).

Separate issue, found on the first real beta1 bench test: commanding
"motor A" moved the peel motor instead of the feed motor — the two
DRV8833 channels drive the opposite motor connectors from what
alpha01-03's `pins_config.h` assumed. Fixed by swapping `PIN_AIN1`/
`PIN_AIN2` with `PIN_BIN1`/`PIN_BIN2` (which channel each firmware role
uses), not by touching `invertMotorA` (which channel's polarity is
inverted) — the two are independent. Because `invertMotorA = true` was
only ever validated against the old (wrong) channel assignment, it's
**unverified against this pin swap** — re-test direction on real
hardware before trusting it; see `beta1/project.md`.

## Not yet in this protocol

- No interrupt-driven UART0 RX — see `alpha01/project.md`'s Modbus
  feasibility section; still a prerequisite before trusting this under
  real bus load with moves in progress.
- No re-addressing flow for an already-assigned feeder (deliberate — see
  `alpha01/project.md` "Addressing scheme, v2").
- No persistence for `invertMotorA`/`invertMotorB` — RAM-only per boot.
- CRC8 (not CRC16) — adequate for this bus's low rate/short frames so
  far; revisit if real-world error rates say otherwise.

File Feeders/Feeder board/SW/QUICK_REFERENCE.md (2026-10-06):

# Feeder Firmware Quick Reference (alpha01 / alpha02 / alpha03 / beta1 / v0.01a / v0.02 / v0.02b)

Debug port: **Serial1**, 9600 baud, newline-terminated, via the ISP header
(D11/D12 — shares that header with ISP flashing, mutually exclusive at any
given instant). Not case-sensitive. `HELP`/`?` prints this list live from
whichever firmware is actually flashed.

Full design rationale for any of this: `alpha01/project.md` /
`alpha02/project.md` / `alpha03/project.md` / `beta1/project.md` /
`v0.01a/project.md` / `v0.02/project.md` / `v0.02b/project.md`. Full RS485
wire protocol spec (opcodes, error codes): **`PROTOCOL.md`**. PC-side
GUI/CLI for the bus: **`tools/README.md`**.

`v0.01a` is the first MAJOR-version release (forked from `beta1`) — same
command set as `beta1` throughout this doc, except `SELFTEST` and the
SW1/SW2-held-at-boot relay button-test mode aren't run automatically on
every boot anymore (both still work on demand, see their entries below).
v0.01a also adds `PEEL <ms>` (peel motor alone, negative = reverse),
makes SW2 run the peel motor for as long as it's held (replaced by the
three button modes in v0.02b, see the *buttons* row), SW1 held >=700ms
= fast feed (one full sprocket turn, also `FASTFEED`), `SNAP` = seat on
the nearest tooth approaching backwards, prints short
`ok`/`ERR: ...` replies instead of long sentences, and has `TRACE` off by
default (one `move N ok <angle>` / `move N ERR <why>` line per move).
Status RGB on v0.01a: yellow = booting, blue = ready, red = error (no
magnet / driver fault), purple = motor moving, white = IDENTIFY.

`v0.02` adds a per-feeder saved peel time (`PEELCAL`, `PEELRUN`,
`CMD_SET_PEEL_TIME`/`CMD_GET_PEEL_TIME`, `CMD_PEEL` with only a direction),
`JOG`/`CMD_JOG`, `I2CSCAN` and `SETSERIAL` for a plain AT24C02, and error
codes `ERR_I2C`/`ERR_LOCKED`. `v0.02b` adds the saved peel rate that ties
peel to feed distance, `CMD_FEED_BACK`, adjustable status-LED brightness,
three button modes and a green flash on bus traffic (see the rows below).

## Bring-up / status

| Command | Does |
|---|---|
| `STATUS` / `WHOAMI` | addr, component, tapeZero, pitch, angle/target, magnet health, i2cErrors (+ `invertA`/`invertB`/`tapeWidthMm`/`lastMoveErr` on alpha02+, `serial=` on alpha03+, `relay=`/`iMonRaw=`/`iMonMa=`/`i5vEstMa=` on beta1, or `[RS485ECHO ON]` banner on alpha01 if active) |
| `HELP` / `?` | print this command list |
| `SIMADDR <n>` | force bus address `n` (1–247) locally, bench-only, skips `CMD_DISCOVER`/`CMD_ASSIGN_ADDR` |
| `LED ON` / `LED OFF` | standard external LED, plain on/off. alpha01/02: D13/PB5 (shares ISP header's SCK line). alpha03+: A3/PC3 (own pin) |
| `IDENTIFY [n]` | **alpha02+** — blink status LED white `n` times (default 3), mirrors `CMD_IDENTIFY` |
| `PEEL <ms>` | **v0.01a+** — run the peel motor alone for `ms` (1–5000, negative = reverse). Stops on a driver fault |
| `PEELCAL [<ms>]` | **v0.02+** — show / save this feeder's fixed peel time (10–5000 ms, internal EEPROM, survives component changes and `RESETCFG`), mirrors `CMD_SET_PEEL_TIME` |
| `PEELRUN [REV]` | **v0.02+** — run the saved peel time (`ERR` if none saved) |
| `FASTFEED` | **v0.01a+** — one full sprocket turn forward (160 mm), same as holding SW1 in feed-only mode |
| `SNAP` | **v0.01a+** — seat on the nearest tooth, always approaching backwards (with a peel rate set, peels in reverse first) |
| `JOG <mm>` | **v0.02+** — relative sprocket move, ±0.1–160 mm (same as `MOVEMM`), mirrors `CMD_JOG`. Never touches the peel motor |
| `I2CSCAN` | **v0.02+** — list the 7-bit addresses that answer on the I2C bus (`0x36` AS5600, `0x50`–`0x57` EEPROM, `0x58`+ AT24CS02 serial page) |
| `SETSERIAL <32 hex>` | **v0.02+** — program a 16-byte serial into a plain AT24C02 (read back and verified); refused if a factory serial exists. Mirrors `CMD_SET_SERIAL` |
| `SETPOS <mm|143r|CLEAR>` / `POS` | **v0.02b+** — set / show this feeder's saved slot position and last assigned address (also in `STATUS`), mirrors `CMD_SET_POSITION` |
| `LEDBRIGHT [<1-255>]` | **v0.02b+** — show / set status RGB brightness (saved, default 40) |
| `PEELRATE [<ms/mm>]` | **v0.02b+** — show / set peel per mm of feed (saved; `0` = off). With a rate set, `FEED`/SW1 peel forward after the sprocket moves, `SNAP` peels in reverse before it moves back. Not used by `FASTFEED`/`MOVEMM`/`GOMM`/`JOG` |
| *buttons* | **v0.02b+** — SW1 = forward, SW2 = reverse, in three modes; SW1+SW2 together step to the next. **Feed only** (blue, boot default): SW1 = feed a tooth (hold = fast feed), SW2 = back a tooth, no peel. **Peel only** (orange): SW1 / SW2 held = peel fwd / rev. **Feed+peel** (green): SW1 = feed then peel, SW2 = peel reverse then back a tooth (needs a peel rate). Peel-only drops back to feed-only after 2 min idle. `MODE [FEED\|PEEL\|BOTH]` shows / sets it from the debug port |
| *status LED* | **v0.02b+** — blue = ready, feed-only mode; orange = ready, peel-only mode; green = ready, feed+peel mode; purple = moving; red = error; yellow = booting; white = identify. A short **green flash** (blue in feed+peel mode) means a frame addressed to this feeder just arrived |
| `SETWIDTH <mm>` | **alpha02+** — set this unit's tape width (8/12/16/24/32/44/56), assembly/bench-time, mirrors `CMD_SET_HW_INFO` (alpha02: ATmega EEPROM; alpha03+: AT24CS02) |
| `SERIAL` | **alpha03+** — print the AT24CS02's factory-programmed 128-bit serial number as hex, mirrors `CMD_GET_SERIAL` |
| `RELAY ON` / `OFF` | **beta1 only** — force the RS485 bus-connect relay, bench-only override, bypasses the 5V-stable gate |
| `SELFTEST` | **beta1 only** — re-run the boot self-test on demand: relay x2 (audible click each way), ext LED, IMON/5V readout. Ends with the relay forced OFF — disconnects a live bus link until `RELAY ON`/reboot |
| *(hold SW1 or SW2 at power-up)* | **beta1 only** — relay button-test mode: RGB blue → red/relay off, then each SW1/SW2 press toggles the relay (green=on/red=off) indefinitely. Not a typed command — power-cycle without holding a button for a normal boot |
| `IMON` | **beta1 only** — print `PIN_I_MON` raw ADC + calibrated mA (TPS26600 IMON, 12V rail current sense) |
| `5VSTATUS` | **beta1 only** — print `PIN_5V_READY` raw ADC (internal 1.1V ref) + calibrated mV + estimated `i5vEstMa` + current relay state |
| `I5V` | **beta1 only** — print estimated 5V-rail current (mA), rough 12V-nominal power-balance estimate from IMON, debug only |
| `CALI <mA>` | **beta1 only** — calibrate IMON: capture current `PIN_I_MON` raw ADC against a real bench-ammeter mA reading, persisted |
| `CALV <V>` | **beta1 only** — calibrate 5V_READY: capture current `PIN_5V_READY` raw ADC against a real bench-multimeter volts reading, persisted |
| `CALSTATUS` | **beta1 only** — print the stored IMON/5V_READY calibration points |
| `CALRESET` | **beta1 only** — reset IMON/5V_READY calibration to the factory-calculated defaults |

## Motion (raw angle/tooth)

| Command | Does |
|---|---|
| `A<deg>` | move to absolute angle, e.g. `A90.0` |
| `T<index>` | move to absolute tooth index 0–39, e.g. `T5` |
| `STEP+1` / `STEP-1` | move ±1 tooth (9°) |
| `STEP+0.5` / `STEP-0.5` | move ±half tooth (4.5°) |
| `ZERO` | re-run DRV8833 still-duty motor calibration (electrical — **not** tape zero, see below) |
| `STOP` | brake motor A (alpha02+: both motors) immediately |
| `TRACE ON` / `TRACE OFF` | toggle live per-move progress logging |

## Tape zero / pitch calibration (per loaded component)

| Command | Does |
|---|---|
| `COMPONENT <id>` | set loaded component id (OpenPnP part id) — **resets tape zero + pitch if the id actually changed** |
| `ZEROHERE` | jog with `STEP`/`T` (whole/half-tooth, no camera) to seat the first pocket's hole, then run this to capture it |
| `PITCH <mm>` | set per-pick feed distance in mm — `4` standard EIA-481, `2` fine, `8`/`12`/`16`/`24` wider multi-hole reels — auto-translated to steps |
| `RESETCFG` | clear tape zero + pitch only (keeps component id) |
| `FEEDCFG <zeroRaw 0-4095> <halfTeeth 1-255>` | set both fields directly (low-level, mirrors `CMD_SET_FEED_CONFIG`) |

## Distance-based motion (mm, not degrees/teeth)

| Command | Does |
|---|---|
| `GOTOZERO` | move to calibrated pick point (tape zero + `PICK_OFFSET_MM`) |
| `GOMM <mm>` | move to tape zero + `PICK_OFFSET_MM` + mm (absolute) |
| `MOVEMM <mm>` | move by mm relative to current position — only needed routinely to (re-)measure `PICK_OFFSET_MM` itself with a camera, not per-reel |
| `FEED` | advance by the configured `PITCH` (next pocket) |

## Firmware-specific

| Command | Firmware | Does |
|---|---|---|
| `RS485ECHO ON` / `OFF` | **alpha01 only** | bypass framed protocol, mirror every RS485 byte straight back out — validates transceiver/wiring/RE-DE turnaround before trusting framing/CRC |
| `INVERTA ON` / `OFF` | **alpha02+** | flip motor A direction (RAM-only, resets on reboot) |
| `INVERTB ON` / `OFF` | **alpha02+** | flip motor B direction (RAM-only, resets on reboot) |

`alpha02`/`alpha03`/`beta1`'s SW1 does a real closed-loop +1 tooth jog
(needs a magnet mounted); SW2 always jogs motor B open-loop on every
firmware (no encoder on that motor). `alpha01`'s SW1/SW2 jog motor A/B
open-loop for bring-up without a magnet. On `beta1`, motor A's direction
defaults *inverted* (`invertMotorA = true`) — the final board's DRV8833
OUT1/OUT2 are swapped relative to the bench units this was tuned on.
Separately, `beta1`'s `pins_config.h` also swaps which DRV8833 channel
(`PIN_AIN1`/`PIN_AIN2` vs `PIN_BIN1`/`PIN_BIN2`) each of those roles uses
— found on the first real bench test, where commanding motor A moved the
peel motor instead (see `PROTOCOL.md` "Motor direction default").

---

## RS485 bus commands (not Modbus — see `PROTOCOL.md` for full detail)

Frame: `[0xAA][ADDR][CMD][LEN][PAYLOAD...][CRC8]`. `ADDR`: `0x00` broadcast
(also "still unassigned"), `1`–`247` unicast. Commands below are beta1's
full set; alpha03 has everything except `CMD_STATUS_INFO`'s last 3 payload
bytes (`iMonRaw`/`relayEngaged` - no I_MON or relay on alpha03); alpha02
additionally lacks `CMD_GET_SERIAL` (and its hw-info commands read/write
the ATmega's internal EEPROM, not an AT24CS02); alpha01 implements
everything up to `CMD_SET_EXT_LED` (no `CMD_SET_INVERT_DIR` or anything
after it) plus its own debug-only `RS485ECHO` transport test mode.

| Command | Code | Payload → | Reply |
|---|---|---|---|
| `CMD_PING` | `0x01` | — | `CMD_PONG` (`0x81`) |
| `CMD_DISCOVER` | `0x10` | broadcast, — | `CMD_DISCOVER_HERE` (`0x90`): `[nonceHi,nonceLo,componentIdHi,componentIdLo,tapeWidthMm]` |
| `CMD_ASSIGN_ADDR` | `0x11` | broadcast, `[nonceHi,nonceLo,newAddr]` | `CMD_ACK` under the new address, only from the matching nonce |
| `CMD_GET_COMPONENT` | `0x20` | — | `CMD_COMPONENT_INFO` (`0xA0`): `[idHi,idLo,zeroHi,zeroLo,feedHalfTeeth]` |
| `CMD_SET_COMPONENT` | `0x21` | `[idHi,idLo]` | `CMD_ACK`/`CMD_NACK` |
| `CMD_SET_FEED_CONFIG` | `0x22` | `[zeroHi,zeroLo,feedHalfTeeth]` | `CMD_ACK`/`CMD_NACK` |
| `CMD_RESET_CONFIG` | `0x23` | — | `CMD_ACK` |
| `CMD_ZERO_HERE` | `0x24` | — | `CMD_ACK` |
| `CMD_SET_PITCH_MM` | `0x25` | `[mm]` (1 byte) | `CMD_ACK`/`CMD_NACK` |
| `CMD_FEED_NEXT` | `0x26` | — | `CMD_ACK` / `CMD_NACK[errCode]` |
| `CMD_SET_EXT_LED` | `0x27` | `[state]` (0=off, nonzero=on) | `CMD_ACK`/`CMD_NACK` |
| `CMD_SET_INVERT_DIR` | `0x28` | **alpha02+** — `[motor(0=A,1=B), state(0/1)]` | `CMD_ACK`/`CMD_NACK` |
| `CMD_GET_HW_INFO` | `0x29` | **alpha02+** — — | `CMD_HW_INFO` (`0xA1`): `[tapeWidthMm]` |
| `CMD_SET_HW_INFO` | `0x2A` | **alpha02+** — `[tapeWidthMm]` | `CMD_ACK`/`CMD_NACK` |
| `CMD_GET_STATUS` | `0x30` | **alpha02+** — — | `CMD_STATUS_INFO` (`0xA2`): `[angleRawHi,angleRawLo,as5600Status,faultActive,lastMoveErr]` + **beta1 only**: `,iMonRawHi,iMonRawLo,relayEngaged` |
| `CMD_STOP` | `0x31` | **alpha02+** — — | `CMD_ACK` |
| `CMD_IDENTIFY` | `0x32` | **alpha02+** — `[blinkCount]` (0⇒3) | `CMD_ACK` (after blinking) |
| `CMD_GET_SERIAL` | `0x33` | **alpha03+** — — | `CMD_SERIAL_INFO` (`0xA3`): 16 bytes, or `CMD_NACK` if the AT24CS02 didn't respond |
| `CMD_PEEL` | `0x34` | **v0.01a+** — `[dir(0=fwd,1=rev), duration×10ms]` | `CMD_ACK` (after the run) / `CMD_NACK` |
| `CMD_SET_PEEL_TIME` | `0x35` | **v0.02+** — `[msHi,msLo]` (10–5000) | `CMD_ACK` (echo) / `CMD_NACK` |
| `CMD_GET_PEEL_TIME` | `0x36` | **v0.02+** — — | `CMD_PEEL_TIME_INFO` (`0xA4`): `[msHi,msLo]`, `0xFFFF` = unset |
| `CMD_JOG` | `0x37` | **v0.02+** — `[hi,lo]` signed 0.1 mm units (±1600) | `CMD_ACK [angleRawHi,angleRawLo]` / `CMD_NACK [errCode]` |
| `CMD_I2C_SCAN` | `0x38` | **v0.02+** — — | `CMD_I2C_SCAN_INFO` (`0xA5`): responding addresses |
| `CMD_SET_SERIAL` | `0x39` | **v0.02+** — 16 serial bytes | `CMD_ACK` / `CMD_NACK [ERR_LOCKED\|ERR_I2C]` |
| `CMD_SET_LED_BRIGHTNESS` | `0x3A` | **v0.02b+** — `[level 1-255]` | `CMD_ACK` / `CMD_NACK` |
| `CMD_SET_PEEL_RATE` | `0x3B` | **v0.02b+** — `[hi,lo]` 0.1 ms/mm (5–5000, 0 = off) | `CMD_ACK` / `CMD_NACK` |
| `CMD_GET_PEEL_RATE` | `0x3C` | **v0.02b+** — — | `CMD_PEEL_RATE_INFO` (`0xA6`): `[hi,lo]`, `0xFFFF` = unset |
| `CMD_FEED_BACK` | `0x3D` | **v0.02b+** — — | `CMD_ACK` / `CMD_NACK [errCode]` — back by the pitch, peel reversed first if a rate is set |
| `CMD_SET_POSITION` | `0x3E` | **v0.02b+** — `[xHi,xLo]` slot position (`0xFFFF` = clear) | `CMD_ACK` (echo) |
| `CMD_GET_POSITION` | `0x3F` | **v0.02b+** — — | `CMD_POSITION_INFO` (`0xA7`): `[xHi,xLo,lastAddr]` |

`CMD_ACK` = `0x82`, `CMD_NACK` = `0x83`. Error codes (in `CMD_NACK`
payloads and `CMD_STATUS_INFO`'s `lastMoveErr`): `0x00` none, `0x01` fault,
`0x02` magnet lost, `0x03` stall, `0x04` timeout, `0x05` bad param, `0x06`
not ready (e.g. feed requested before calibrated), `0x07` I2C/EEPROM
problem (v0.02+), `0x08` locked (v0.02+). Full detail:
`PROTOCOL.md`.

---

## Two common bench sequences

**Load a reel / calibrate a component:**
```
COMPONENT 12
ZEROHERE          (after jogging STEP/T so the first pocket's hole is seated)
PITCH 4
FEED              (repeat per pick)
```

**Validate RS485 hardware (alpha01 only, needs a second USB-RS485 adapter):**
```
RS485ECHO ON
```
then send arbitrary bytes from the adapter's terminal and confirm they
come back unchanged — one byte at a time, exercising RE/DE turnaround on
every byte. `RS485ECHO OFF` to resume normal framed operation.

**Find a physical feeder by its bus address (alpha02+, over the bus):**
```
CMD_IDENTIFY -> feeder blinks its status LED white 3x
```
or `IDENTIFY` on its own debug port for the same effect locally.

**Read a feeder's factory serial number (alpha03+):**
```
SERIAL
```
or `CMD_GET_SERIAL` over the bus. Needs an AT24CS02 actually populated —
not present on any V0.2a board built so far, only on beta1 hardware.

**Check power-up sequencing on the bench before the divider/relay exist (beta1 only):**
```
RELAY ON       (bypass the 5V-stable gate to test the bus manually)
5VSTATUS       (see the raw internal-1.1V-ref reading and current relay state)
```
Normal boot waits for `PIN_5V_READY` to read stable for 500ms before
engaging the relay on its own — see `PROTOCOL.md` "Power sequencing" for
the reference gotcha this reading works around.

**Hand-calibrate IMON/5V_READY on a bench jig (beta1 only):**
```
CALI 87.5      (with a real ammeter reading 87.5mA on the 12V input right now)
CALV 5.02      (with a real multimeter reading 5.02V on the 5V rail right now)
CALSTATUS      (confirm the stored points)
```
Each command captures the live raw ADC reading against the value you
measured and persists it — future `IMON`/`5VSTATUS`/`STATUS` reads convert
through that point instead of the factory-calculated default. `CALRESET`
undoes both.

**Re-run the full hardware self-test without rebooting (beta1 only):**
```
SELFTEST
```
Relay clicks on/off twice (listen for it), ext LED flashes, then prints
the current IMON/5V readout — same sequence `setup()` runs once at boot.
Ends with the relay forced OFF, so if the feeder was already talking to
a live bus, that link drops until `RELAY ON` or a reboot re-engages it.

**Listen to the relay click for as long as needed (beta1 only, no console needed):**
Hold `SW1` or `SW2` while powering the board up. RGB goes blue, then red
once released (relay off) — from there every button press toggles the
relay and the RGB (green=on/red=off), indefinitely. Power-cycle without
holding a button to get a normal boot back.

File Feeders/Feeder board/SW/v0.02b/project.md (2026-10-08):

# v0.02b

Forked from `v0.02`. Everything in `v0.02/project.md` (and `v0.01a/`,
`beta1/` behind it) still applies; this file only covers what is new.
Protocol details are in `../PROTOCOL.md`.

**Status:** syntax-checked with `avr-g++` against the Arduino AVR core and
`Adafruit_NeoPixel` (no errors, no `-Wall` warnings; PlatformIO itself
could not be run in the authoring environment, so flash/RAM sizes are not
measured). **Not yet run on a real board.**

## What's new

1. **Status RGB brightness is adjustable and saved.** `LEDBRIGHT <1-255>`
   (debug) / `CMD_SET_LED_BRIGHTNESS` (`0x3A`). Stored in the ATmega EEPROM
   (`LedCfg` at 48, CRC'd), applied immediately. Default is now 40 (was a
   fixed 128). An SK6812 channel draws ~18 mA at 255, so a single blue
   channel at 40 is ~3 mA, yellow (two channels) ~6 mA. Tune by eye with
   `LEDBRIGHT`; `STATUS` prints `led=`. Brightness change re-sets the last
   color from its raw value (NeoPixel's `setBrightness` rescales stored
   pixels lossily).

2. **Peel is tied to feed distance.** New per-feeder `PeelRate`
   (`PEELRATE <ms/mm>` / `CMD_SET_PEEL_RATE` `0x3B`, read with
   `CMD_GET_PEEL_RATE` `0x3C`): milliseconds of peel-motor run per mm of
   sprocket travel, stored in 0.1 ms/mm units (EEPROM 52, CRC'd, survives
   component changes and `RESETCFG`, like `PeelCal`). Unset = no coupling,
   exactly v0.02 behaviour (`PEELRATE 0` clears it).
   - **Forward feed** (`FEED`, `CMD_FEED_NEXT`, SW1 in feed+peel mode): the
     peel motor runs forward for the full `rate x mm`, starting **once the
     sprocket has travelled `PEEL_START_MM` (2 mm)**, so on a feed longer than
     that the two overlap ("peel as we go", e.g. 4 mm at 325 ms/mm = 1300 ms
     starting at the 2 mm point). A feed of 2 mm or less peels after it
     finishes. The peel is a background job (`PeelJob`) that the move loop
     services every pass, so the sprocket keeps its single continuous move
     (no stop at 2 mm); if the feed fails, the peel is aborted, and the call
     returns only when both are done. Both motors run together for part of
     the feed, so their currents add (the peel ramps in over 100 ms). Peel is normally *after* feeding: the carrier advances
     and the cover tape comes off at the peel point afterwards.
   - **Backward seat** (`snapToToothBackward()`, i.e. `SNAP` and the seat
     after boot homing): the peel motor runs in *reverse first* by
     `rate x backwardMm`, then the sprocket moves back. Reason: going back
     against already-peeled cover tape is hard; reversing the peel first
     gives it slack. Same rate in both directions, so the amounts match
     because the sprocket distance matches. Skipped below 0.3 mm.
   - Sequential, not simultaneous: two motors starting at once would stack
     their breakaway currents on the 5V rail / 12V eFuse (the problem the
     soft-start work in v0.01a was for). Proportional in amount, ordered in
     time.
   - **Not coupled:** fast feed (tape loading), `CMD_JOG`, `MOVEMM`, `GOMM`,
     `STEP`/`T`/`A`. Those are loading/calibration moves; they leave the
     peel motor alone.
   - Peel run time is capped at 5 s per action (`PEEL_CMD_MAX_MS`). A
     peel-time DRV8833 fault returns `ERR_FAULT`.
   - Consequence for a host: `CMD_FEED_NEXT` now replies after
     move + peel. A host that also sends `CMD_PEEL` after each feed would
     peel twice once a rate is set. The PC GUI's "feed only" cycle option
     is the right one then.
   - `PEELCAL`/`PEELRUN`/`CMD_PEEL` (fixed-duration peel) are unchanged.
     `PEELCAL` is a fixed time with no distance attached; `PEELRATE` is
     the distance-proportional one. The v0.02 open question ("a 2 mm and
     an 8 mm feed need different amounts of peel") is what this answers.

3. **Buttons: three modes, SW1 = forward and SW2 = reverse in each.**
   SW1+SW2 pressed together step to the next mode (feed only, peel only,
   feed+peel, then back to feed only). The order matches how a reel is set
   up: load the tape by hand, then tension the cover tape, then test real
   advances.
   - **Feed only (blue, boot default).** SW1 short = feed one tooth, SW1
     hold >= 700 ms = fast feed one turn (tape loading), SW2 = back one
     tooth. The peel motor is never touched.
   - **Peel only (orange).** SW1 held = peel forward, SW2 held = peel in
     reverse, each only while held (10 s cap), for tensioning by feel. Falls
     back to feed-only after 2 min without a press
     (`PEEL_MODE_IDLE_TIMEOUT_MS`), so a forgotten mode can't turn the next
     SW1 press into an unexpected peel.
   - **Feed+peel (green).** SW1 = feed one tooth, then peel by the
     `PeelRate`; SW2 = peel in reverse first, then back one tooth. Without
     a rate saved it behaves like feed-only. One tooth per press even if
     held. Fast feed is feed-only on purpose: it is a loading move.
   - `MODE` / `MODE FEED|PEEL|BOTH` on the debug port shows or sets it;
     `STATUS` prints `mode=`.
   - Colors are `ledReady()`; orange (255,90,0) and green are the new ones.
     Orange sits near yellow (booting) and red (error): both have a very
     different green channel, but pick another if it reads badly on your
     LED. In feed+peel mode, where steady green is the mode color, the
     bus-activity flash is blue instead.
   - Press both within an 80 ms window (`CHORD_WINDOW_MS`) to step. The
     window means every single press waits up to 80 ms before acting, so a
     chord never fires as a feed first. After a chord both buttons must be
     released before anything else registers.
   - The held-through-boot guard is kept: a button down at power-up isn't
     armed until released once.
   - New bus command `CMD_FEED_BACK` (`0x3D`): back up by the configured
     pitch, peel reversed first when a rate is set. The mirror of
     `CMD_FEED_NEXT`; it lets the PC tools test the backward case, which
     the buttons only reach in feed+peel mode.

4. **Green flash on bus traffic.** Whenever a frame addressed to this
   feeder arrives (unicast, or broadcast once it has an address), plus its
   own discovery/assign replies, the status RGB flashes green for 80 ms
   (`RX_FLASH_MS`), so on a bus with several feeders it is obvious which
   one is answering. In peel mode, where steady green already means the
   mode, the flash is blue. Frames for other addresses and CRC failures do
   not flash. A move or peel started by the frame turns the LED purple
   right away; the flash only holds off the idle repaint. Brightness
   follows `LEDBRIGHT`.

5. **PC tools** (`../tools/`): the GUI was reworked for first tests (live
   feeder card, bring-up checklist, peel-rate helper, LED brightness,
   remembered settings, always-visible STOP) and `sim_feeder.py` lets it be
   tried without hardware. See `../tools/README.md`.

6. **TAP-Jig test build.** `pio run -e atmega328pb_isp_test` builds the same
   firmware with `-DTAPJIG_TEST`: no boot homing, no button actions (buttons
   are only reported), the status RGB can be held, and four extra commands
   (`CMD_T_INPUTS/UPTIME/RGB/MOTOR`, `0x40`-`0x43`) for the test-and-program
   jig. Same fuses as the production env. The production build contains none
   of it and ignores those opcodes (the jig's final stage relies on that).
   Both builds were only compile-checked. See `../tools/TAPJIG.md`.

7. **Tape width: ATmega EEPROM, with a debug override.** The width lives in
   the ATmega's internal EEPROM (location 64), not on the AT24, which holds the
   serial number only for now. The internal EEPROM survives reflashing and the
   jig's chip erase because `EESAVE` is programmed. `TAPE_WIDTH_OVERRIDE`
   (default 1, a temporary debug switch near `loadHwInfo()`) lets any build set
   it with `SETWIDTH` / `CMD_SET_HW_INFO`; set it to 0 to lock it down, after
   which only the `TAPJIG_TEST` build (the jig's stage 14) can write it and
   production answers `ERR_LOCKED`.

   The AT24 is write protected in the field: `at24csWriteBytes()` refuses
   outside the test build, so production firmware never writes it (that covers
   `CMD_SET_SERIAL`, which needs the test build; the jig must release WP while
   it writes a serial).

8. **Slot identity: last address + position X.** The address is still
   disposable (unassigned at every boot). Two things are now remembered
   (EEPROM 68): the last assigned address and a host-set position `posX`
   (`CMD_SET_POSITION`/`SETPOS`, opaque uint16, suggested 0.1 mm along X).
   While unassigned, `CMD_DISCOVER_HERE` also carries `[lastAddr, posX]`.
   Intended host flow (OpenPnP): broadcast `CMD_DISCOVER`; if every reply
   reports the `(lastAddr, posX)` the saved layout expects (and no address is
   claimed twice), re-assign each one its old address with
   `CMD_ASSIGN_ADDR` and skip the rest of setup; any mismatch, a feeder with
   `lastAddr` 0, or an unexpected extra feeder means the layout changed, so
   fall back to normal assignment. `posX` is a consistency check, not proof
   (two feeders can be swapped on the same positions); confirm with vision.
   The GUI Setup tab shows both columns in the scan list, **Restore
   addresses** does the flow above (refusing duplicates), and **Slot
   position X** saves it. Not tested on hardware.

9. **Homing: nearest tooth, staggered by last address.** Boot homing
   (`calibrateZero()`) no longer moves back to where it started and never goes
   to the tape zero: after the duty ramps it seats on the NEAREST tooth of the
   grid (`snapToTooth(false)`, at most 4.5 deg / 2 mm either way). The pick
   position is reached later by relative moves from that tooth. `SNAP` and
   other seats still approach backwards only. Homing timing: boot, then the magnet must be
   detected continuously for a random 1-3 s (`HOMING_MAGNET_STABLE_MIN/MAX_MS`,
   was a fixed 5 s), then a further 0-5 s that is a fixed function of the
   previous bus address (`HOMING_SPREAD_MAX_MS`, golden-ratio hash so
   consecutive addresses land far apart and the same feeder always gets the
   same slot; random for a feeder with no remembered address), then homing,
   if the magnet is still there. The spread comes AFTER the stable wait, so
   all feeders reach it within about 2 s of each other and the 5 s window
   then separates them. Homing takes about 1-2 s, so a big bus can still
   overlap a few feeders; widen `HOMING_SPREAD_MAX_MS` if the rail still
   sags.

## Open questions

Everything open in `v0.02/project.md` and `v0.01a/project.md` still is, plus:

- **`PEELRATE` has no default and no measured value.** v0.02's
  `PEELCAL 1570` was for an unstated distance. Measure: peel ms for a known
  feed (e.g. a 4 mm tooth) until the cover tape stays taut, divide by the
  mm.
- Whether the forward peel should start slightly *before* the feed ends
  (overlap) instead of strictly after is untested; strictly after is the
  safe choice for the current budget.
- Reverse peel before a backward seat is applied on the boot-time seat as
  well. If the cover tape isn't threaded yet it just spins the peel motor
  for under one tooth's worth.
- SW2 back-one-tooth in feed-only mode moves the sprocket backwards with no
  peel slack, by design (the peel isn't involved in that mode). Backing out
  a tape that is already under peeled cover tape is a feed+peel job.
- Brightness default (40) is a guess for "visible but cheap"; adjust on the
  bench.
- Not built with PlatformIO here: confirm flash/RAM on the real toolchain.
  The first flash does not change fuses relative to v0.02.

## Build / flash

Same as v0.02 (`flash.ps1`, `pio run -e atmega328pb_isp -t upload`).

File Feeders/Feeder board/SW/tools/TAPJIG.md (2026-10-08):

# TAP-Jig (test-and-program jig): host software

Host side of the jig described in the spec doc "OrionPnP Feeder Programming &
Test Jig". The **Production** tab of `rs485_gui.py` runs the whole 18-stage
routine (pre-power checks through release) against a feeder seated in the
cradle, logs pass/fail per unit, and programs the unit. The same engine runs
headless with `tapjig_run.py`.

Status: written and exercised against `sim_jig.py` only. **The 32u4 jig
firmware does not exist yet** (the protocol below is what it has to
implement), the test-firmware commands have only been compile-checked, and
every numeric limit in the routine is a placeholder. Nothing here has touched
real hardware.

## Pieces

| File | What |
|---|---|
| `tapjig_engine.py` | `JigLink` (line protocol to the 32u4), `Dut` (feeder via the jig's RS-485 passthrough), `Isp` (avrdude/USBasp), `Runner` (executes a routine), `write_log` |
| `tapjig_routine_feeder_v03.json` | the routine: stages 0-17 from the spec, as data (steps, limits) |
| `tapjig_run.py` | CLI runner (exit 0 = PASS) |
| `rs485_gui.py`, Production tab | the operator UI around the same engine |
| `sim_jig.py` | simulated jig + simulated feeder behind it, for development (`--fail NAME` injects a fault) |
| `../v0.02b` env `atmega328pb_isp_test` | the DUT **test firmware** (`-DTAPJIG_TEST`) |

## Flow

```
host PC ──USB-CDC (line protocol)──> jig ATmega32u4 ──RS-485 (UART1)──> DUT
   │                                      │ ADS1115, LDRs, servo, AO3400 switches, encoders, PSU
   └──avrdude + USBasp ───────────────────┴── ISP pogo pins ───────────> DUT
```

The host talks only to the 32u4. It never needs a second USB-RS485 adapter:
DUT frames are tunnelled through the jig (`RS485` command), built and parsed
with the same `rs485_protocol.py` the rest of the tools use. ISP is run by the
host with avrdude; the jig is told afterwards (`ISPDONE`) so it can release or
power-cycle the DUT.

1. The operator seats the board, picks the **tape width** (a unit option, not
   a measurement), presses **Run all stages**.
2. The engine runs the stages in order, stops at the first failed stage
   (option), and always ends with `SAFE` (PSU off, switches released, servo
   parked), whatever happened.
3. A full run writes `production_logs/<date>/<SN>_<time>_<PASS|FAIL>.json`
   (every check with the values it saw, every saved measurement) and appends a
   line to `production_logs/summary.csv`. A "Run selected stage" run is a
   debugging aid and is not logged.

The serial number comes from the AT24CS02 factory page (stage 10). The unit is
identified by it in the log; a run that fails before stage 10 logs as
`NOSERIAL`.

## Jig line protocol (what the 32u4 must implement)

ASCII, one request line, one reply line, `\n` terminated, 115200 baud.
Reply is `OK key=value ...` or `ERR reason`. Numbers are decimal. Everything
blocks until done unless noted. The host gives up after 3 s (RS485: its own
timeout + 2 s).

| Request | Reply | Meaning |
|---|---|---|
| `HELLO` | `OK fw=<v> rev=<n>` | identify |
| `SAFE` | `OK` | PSU off, SW1/SW2/RESET released, servo parked, stalls released. Must always work |
| `PSU ON <limit_mA>` / `PSU OFF` | `OK` / `ERR TRIP` | jig supply to the DUT with the tight current limit (software fault detection per the spec: deglitch, hysteresis, latch) |
| `STATE` | `OK psu=<0/1> latched=<0/1> ma=<n>` | PSU on, current-limit trip latched, input current (INA293) |
| `REARM` | `OK` | clear a latched trip (explicit, never automatic) |
| `COLD VIN\|V5\|VMOT` | `OK ohms=<n>` | pre-power resistance via the 10 kOhm sniff; 0 = short, large = open; settle delay inside |
| `CONT VIN_PRE_POST\|GNDP\|MODE_RTN\|R485_POST` | `OK ohms=<n>` | continuity/resistance between the named points |
| `ADC FB\|VIN\|V5\|VINPROT\|IMON` | `OK mv=<n>` | ADS1115 reading **at the DUT node** (divider already undone) |
| `ADC IIN` | `OK ma=<n>` | jig's own input-current reading |
| `DIG FAULT\|V5RDY\|FLT\|EN485` | `OK v=<0/1>` | digital reads (FAULT, FLT# are active low: 1 = not asserted) |
| `SW SW1\|SW2 <0/1>` | `OK` | 1 = force low (button pressed) |
| `RESET <ms>` | `OK` | pulse RESET low |
| `LDR FIBER\|RGB <samples>` | `OK raw=<0-1023>` | averaged ADC of the LDR |
| `SERVO <deg>` | `OK` | position the magnet arm (waits for the move) |
| `STALL <1\|2> <0/1>` | `OK` | hold / release reference motor 1 or 2 so the DUT's drive really stalls (**mechanism undefined, see open items**) |
| `ENCARM <ch> <window_ms>` | `OK` | start timing reference encoder `ch` (non-blocking) |
| `ENCREAD <ch>` | `OK pulses=<n> rev_ms=<n>` | result: pulses and measured full-revolution time (0 if it never spun) |
| `RS485 <hex frame> <timeout_ms>` | `OK frames=<hex> de=<0/1> n=<bytes>` | transmit one frame on UART1, collect everything received for `timeout_ms`; `de` = RE/DE pogo was seen asserted while the DUT answered |
| `ISPDONE test\|production` | `OK` | host finished programming; release/power-cycle the DUT so the new firmware runs |

The jig keeps every output in a safe state on boot and on USB disconnect.

## DUT test firmware

`pio run -e atmega328pb_isp_test` builds `v0.02b` with `-DTAPJIG_TEST`. Same
fuses as production (the spec requires no extra fuse pass), but:

- no boot homing and no button actions (buttons are only *reported*);
- the status RGB can be held by the jig;
- extra commands (production firmware ignores them, which stage 16 uses to
  prove the production build is running):

| Command | Code | Payload | Reply |
|---|---|---|---|
| `CMD_T_INPUTS` | `0x40` | - | `0xB0`: `[flags,imonHi,imonLo,v5Hi,v5Lo]`; flags b0 SW1 down, b1 SW2 down, b2 DRV nFAULT low, b3 relay coil on, b4 magnet detected |
| `CMD_T_UPTIME` | `0x41` | - | `0xB1`: `[ms x4 big-endian, MCUSR at boot]` (bit 1 = external reset) |
| `CMD_T_RGB` | `0x42` | `[r,g,b]` (all 0 = release) | `CMD_ACK` |
| `CMD_T_MOTOR` | `0x43` | `[motor 0=A/1=B, dir, ms/10]` | `CMD_ACK [faultSeen]`; open loop, full duty with soft start, stops on a DRV fault |

Everything else the stages need already exists in v0.02b: `CMD_PING`,
`CMD_GET_STATUS`, `CMD_I2C_SCAN`, `CMD_GET_SERIAL`, `CMD_SET_EXT_LED`,
`CMD_SET_HW_INFO`/`CMD_GET_HW_INFO`, `CMD_SET_SERIAL`, discovery/assign.

## Routine format

`tapjig_routine_feeder_v03.json`: `stages[]`, each with `steps[]` and an
optional `cleanup[]` (always runs). A step is one of:

- `{"do": "jig.adc", "node": "FB", "save": "fb"}` an action, result saved as `fb`
- `{"check": "between(fb.mv, 1180, 1260)", "label": "..."}` a check
- `{"wait_ms": 800}`, `{"prompt": "message"}` (operator OK/Cancel)
- any step may carry `"if": "<expression>"`; a check may carry `"advisory": true`
  (recorded, never fails the stage - for limits that are not calibrated yet)
- an action parameter starting with `=` is an expression: `"mm": "=opt.tape_width_mm"`

Expressions are evaluated by a whitelisting evaluator (comparisons, `and/or/not`,
arithmetic, attribute and index access, and `between within abs min max len
round angdiff angdist any all`); nothing else is callable. Names available:
saved results, `opt` (unit options: `tape_width_mm`, `operator`), `p`
(routine `params`), `unit.serial`.

Actions: `jig.hello/safe/rearm/state/cold/cont/psu_on/psu_off/adc/dig/sw/
reset_pulse/ldr/servo/stall/enc_arm/enc_read`, `dut.discover_assign/ping/
status/i2c_scan/serial/inputs/uptime/rgb/ext_led/motor/hw_info/write_width/
write_serial`, `isp.program`, `util.sleep`. Add a limit or a stage by editing
the JSON; add a new kind of action in `Runner._build_actions`.

## Running it

GUI: `python rs485_gui.py`, Production tab: connect the jig port, point at the
routine and the two `.hex` files (`pio run -e atmega328pb_isp_test` and
`pio run -e atmega328pb_isp`; both under `.pio/build/<env>/firmware.hex`) and
avrdude, choose the tape width, **Run all stages**. Click a stage to see its
checks and measured values. **Stop** aborts at the next step and still puts the
jig in its safe state.

CLI: `python tapjig_run.py --port COM7 --test-hex ... --production-hex ... --tape-width 12`.

No hardware: `python sim_jig.py`, then connect to the path it prints with
**Dry-run ISP** ticked (or `--dry-isp`). `--fail cold_short|fb_low|no_as5600|
no_serial|no_fiber|stuck_sw1` makes one thing wrong.

## Mapping to the spec's stages

| # | Stage | Notes |
|---|---|---|
| 0 | Pre-power | cold resistance VIN/5V/VMOT, VIN pre/post-fuse continuity, GNDP, MODE not bridged |
| 1 | Power-up | PSU on at 300 mA, no latched trip, FB, 5V, VIN, VINPROT, 5VRDY, FLT#, idle current |
| 2 | Flash test FW | fuses, erase, write+verify, then the DUT must answer discovery and ping |
| 3 | SW1/SW2 | AO3400 forcing, read back with `CMD_T_INPUTS` |
| 4 | RESET | pulse, DUT re-announces, MCUSR shows an external reset |
| 5 | Fault line | real stall of motor A, DRV fault trips and clears; LDR value recorded as **advisory** |
| 6 | Fiber LED | `CMD_SET_EXT_LED` + LDR on/off delta |
| 7 | RGB LED | `CMD_T_RGB` R/G/B + LDR delta each, distinct |
| 8 | AS5600 flat | I2C scan shows 0x36 and 0x50, status reports no magnet |
| 9 | AS5600 magnet | servo sweep, angle follows in steps |
| 10 | AT24CS02 SN | factory serial read, becomes the unit's identity |
| 11 | Motors + encoders | A -> M1, B -> M2: drive 1 s, encoder revolution time, no DRV fault |
| 12 | RS-485 logic | ping works and RE/DE was seen asserted |
| 13 | RS-485 bus | real frames, relay commanded (EN_485_COIL + `inputs.relay`), post-relay continuity, IMON vs the jig's current |
| 14 | Write EEPROM | tape width + read-back; serial only if the chip has no factory serial |
| 15 | Flash production FW | erase + write + verify, no fuse pass |
| 16 | Final confirm | SN and tape width read back; test-only command no longer answers |
| 17 | Release | PSU off |

## Open items (need a decision or a measurement)

- **AT24 write protect**: the DUT's AT24 is write protected and only holds the
  serial number. A plain AT24C02 needs the jig to release WP while the test
  firmware writes the serial (stage 14); not yet a jig command or routine step.
  The tape width is in the ATmega EEPROM, so no WP handling is needed for it.

- **Jig firmware**: the 32u4 side of the protocol above is unwritten.
- **Limits**: every number in the routine is a nominal-value guess. Calibrate on
  a known-good unit, in particular LDR deltas (stages 6, 7), encoder revolution
  time (11), IMON agreement (13), idle current (1).
- **Stage 5 stall**: the spec says "real motor stall, not forced". How the jig
  holds a reference motor (`STALL`) is undefined; the routine assumes motor A
  <-> M1. The LDR check is advisory because the "fault LED" has no LDR in the
  spec and the status RGB shows red for several reasons (no magnet, fault).
- **Fuse bytes** in the routine (`E2/D7/FD`) are my reading of what `pio run -t
  fuses` burns for this board: verify with `pio run -e atmega328pb_isp -t
  fuses -v` before the first production run.
- **Stage 14 serial**: the spec says "serial number + tape width" are written,
  but an AT24CS02's serial is factory read-only. The routine writes a serial
  only when none exists (plain AT24C02). If you want jig-assigned serials,
  that needs a decision.
- **TPS26601 SHDN#/pin 14** (spec open item) has no test here: the spec says it
  may not be pogo-toggleable; add a stage once that is settled.
- Which stages the DUT-side commands cover when the board has no magnet
  (stage 5 and 8 assume the servo arm is parked away).

## TODO: portable production station (Raspberry Pi) and multi-product support

Target hardware: Raspberry Pi 3B (1 GB) + 7" 1024x600 IPS capacitive touch
HDMI monitor (USB-powered, USB touch), everything from one 5 V supply
(about 5 V / 4-5 A; the jig needs a 5->12 V boost for the DUT's VIN). Not
started; decisions so far:

- [ ] Hardware direction for a universal base (resource budget, fixture
      connector, fixture/jig profiles, safety): see
      `TAPJIG_UNIVERSAL_BASE.md`.
- [ ] **Separate kiosk app** for production (keep `rs485_gui.py` as the
      engineering tool): fullscreen 1024x600, touch-sized buttons, product
      selector, big PASS/FAIL banner, stage list, run/stop. No packet
      builder, calibration or peel controls. Settings behind a long press.
      On-screen keyboard for the rare text entry (operator name).
- [ ] **Split the engine into a package** (runner, expression checks, ISP,
      logging) shared by both apps and `tapjig_run.py`.
- [ ] **Product folders** (data only): `product.json`, routine, test and
      production hex, fuse bytes, per-unit options (e.g. tape widths),
      `requires_jig`. A `current.json` pointer chooses the release rather than
      "newest file".
- [ ] **Jig profile**: which jig this is and what it supports (commands,
      nodes, ISP part); the jig's `HELLO` reports its type. Reject a routine
      that needs something the jig lacks before the run starts. Selector
      auto-picks the product when only one matches the jig.
- [ ] **Pluggable DUT command layer** per product (feeder: RS-485 frames;
      mainboard: TBD once its test interface is known). Plugins live in the
      repo, never on the share.
- [ ] **SMB share** (`cifs` mount): sync the selected release to local disk
      and verify checksums before a run (a network drop must not interrupt a
      flash); write logs locally first, then copy them to the share; record
      release version and hashes in every unit log.
- [ ] **Pi setup notes**: autostart in kiosk mode, udev rules (jig, USBasp),
      avrdude install, undervoltage check, read-only root or at least a
      writable log partition.

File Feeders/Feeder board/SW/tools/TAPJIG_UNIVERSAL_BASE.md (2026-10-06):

# TAP-Jig universal base: considerations

Status: **concept notes, nothing designed or built.** Written from a design
discussion; every number below is a starting proposal to challenge, not a
requirement. The current feeder jig (see `TAPJIG.md` and the spec doc
"OrionPnP Feeder Programming & Test Jig") is the first product to use this
idea, not the finished universal base.

## Idea

One **universal base** that offers a fixed, generous set of named hardware
resources, and **per-product fixtures** (a pogo adapter plus any ancillary
parts: motors, LDRs, sensors, servo) that simply connect product signals to
known base pins. What a pin *does* is chosen in configuration, not in
hardware. The test routine talks about **signals** (`SW1`, `V5`,
`FIBER_LDR`), a fixture profile maps signals to base resources, and a jig
profile says what the base can do.

```
Pi (UI, routine, logs, avrdude/OpenOCD) --USB--> hub --> base controller (real time, safety)
                                                    \--> programmers (USBasp, J-Link, ...)
base controller --> power rails, analog, digital I/O, buses --> fixture connector
                                                                  --> pogo board --> DUT
                                                                  --> ancillary (motors, LDRs, sensors, servo)
```

Fixture = pogo board + mechanics + ancillary parts + an ID EEPROM. Swapping
products = slide the fixture in, clamp it, select (or auto-detect) the
product.

## Is "bigger and universal" the right call?

Yes if more than one product will be tested, with caveats:

- It moves variability from hardware to config. That is the point, and it is
  what makes a second product cheap.
- It is a real project: more parts, more protection, more firmware. Build the
  current feeder jig first and keep its pin names and fixture connector
  convention compatible with this, rather than waiting for the universal base.
- The 32u4 will not fit a base this size (pins, peripherals). Pick the
  controller for the budget below (RP2040/RP2350, an STM32, or a larger AVR),
  or let the Pi drive I2C/SPI expanders directly and keep only the real-time
  and safety work (watchdog, current limits, capture timing) on a small MCU.
- **Alternative worth considering:** a backplane with plug-in cards (power
  card, digital I/O card, analog card, comms card) instead of one big board.
  Same resources, but you build and debug one card at a time and only
  populate what a product needs.

## Resource budget (proposal)

| Resource | Proposal | Notes |
|---|---|---|
| Power rails to DUT | **5 V, 12 V, 24 V**, "beefy" (several A each) | each switchable, with soft start, hardware overcurrent limit (programmable), current and voltage sense, discharge on off; Kelvin (4-wire) sense out to the fixture |
| Aux 3.3 V | on signal pins only | low current; external 3.3 V loads are expected to be few and small |
| Logic reference | per-bank Vio (1.8 / 3.3 / 5 V), set by the fixture | all digital I/O follows it |
| Digital I/O | 64 lines via several expanders | each line: input / push-pull / open-drain low / weak pull-up or pull-down; series resistor and clamp at the connector |
| Analog inputs | 16 channels, 16-bit class ADCs | fixture provides scaling; base measures a clean range (e.g. 0-5 V and a 0-2.5 V precision range) |
| Analog outputs | 2-4 DAC channels | thresholds, bias, simulated sensors |
| UART | 4 TTL, 2 RS-485 (switchable termination), 1 CAN | named ports, configurable baud |
| I2C | 2 buses + a mux | pull-ups selectable, Vio-referenced |
| SPI | 2 buses with chip selects | |
| Programming | **SWD** (J-Link or CMSIS-DAP/ST-Link) **and AVR ISP** (USBasp) | programmers are USB devices on the Pi hub; base only routes their lines (and RESET) to fixture pins |
| PWM / servo | 4 outputs | magnet arm, motor speed |
| Timer capture / counters | 4 inputs | encoder timing, frequency |
| Optical/other sensors | via analog inputs | LDRs live on the fixture |
| Button/reset forcing | digital lines in open-drain low mode | replaces dedicated MOSFETs per product |
| Fixture ID | I2C EEPROM on the fixture | read on insertion; holds fixture type, revision, serial and a profile pointer |
| Interlock | "fixture seated and closed" input | no rail enables without a valid ID and a closed fixture |

J-Link note: the cheap EDU/EDU Mini variants are non-commercial licence only.
For production use buy the right licence or use an alternative probe
(CMSIS-DAP, ST-Link) driven through OpenOCD/pyOCD.

## Fixture connector and pin naming

- One rugged connector (board-to-board or card edge), multiple contacts per
  power line, locating dowels, keyed so it cannot be inserted rotated.
  Order of magnitude: 150-200 contacts for the budget above; a bigger number
  argues for the backplane idea.
- Base pins have **fixed names**: `D00..D63`, `A00..A15`, `AO0..AO3`,
  `UART0..UART3`, `RS485_0..1`, `I2C0..1`, `SPI0..1`, `SWD`, `ISP`,
  `PWM0..3`, `CAP0..3`, `P5V`, `P12V`, `P24V`, `V3V3`, `GND`...
- A signal that needs more than the base can give (very high current, a
  special analog front end) stays on the fixture, not in the base.

## Configuration model

Three layers, all data, none of it code:

1. **Jig profile** (the base): what exists and its limits: rails and current
   limits, ADC ranges, counts of each bus, supported commands. The base
   reports its type and revision in `HELLO`.
2. **Fixture profile** (stored on or alongside the fixture): which base pin
   carries which product signal, and in what mode.
3. **Product package** (routine, test and production firmware, fuses/option
   bytes, per-unit options): refers to **signals only**, never to base pins.

Illustrative fixture profile fragment (format not fixed):

```json
{
  "fixture": "feeder_v03_cradle", "rev": 1, "jig": "universal_v1",
  "rails": { "VIN": {"rail": "P12V", "limit_mA": 300}, "V5": {"sense": "A02"} },
  "signals": {
    "SW1":   {"pin": "D07", "mode": "od_low"},
    "SW2":   {"pin": "D08", "mode": "od_low"},
    "RESET": {"pin": "D09", "mode": "od_low"},
    "FAULT": {"pin": "D10", "mode": "in", "active": "low"},
    "FB":    {"pin": "A00", "range": "2.5V", "scale": 1.0},
    "VIN_S": {"pin": "A01", "range": "5V", "scale": 4.3},
    "RGB_LDR": {"pin": "A08", "range": "5V"},
    "SERVO": {"pin": "PWM0"},
    "BUS":   {"port": "RS485_0", "baud": 9600}
  },
  "programmer": { "type": "avr_isp", "lines": {"MOSI": "D20", "MISO": "D21", "SCK": "D22", "RESET": "D23"} }
}
```

The routine then says `jig.sw SW1 pressed` or `jig.adc FB`; the engine looks
the signal up in the fixture profile. The current routine already uses names
rather than pins, which is why this is a small step.

## Safety and power (the big difference from the feeder jig)

The feeder jig's spec chose software-only fault detection because the
currents are small and a pre-power resistance check screens out dead shorts.
That reasoning does not carry over to several-amp 24 V rails:

- hardware current limit and trip per rail (hot-swap controller / eFuse
  class), software only sets and reads it;
- hardware watchdog that drops every rail if the controller or the USB link
  stops talking;
- the interlock above, plus a physical e-stop that cuts the rails
  independently of firmware;
- pre-power cold-resistance check on every rail the product uses, soft start,
  and a discharge path so a board is not handled while a rail is still up;
- latched faults that need an explicit re-arm, as in the feeder jig;
- ESD protection and series resistance on every connector line, since pogo
  contacts are touched by people and by boards.

## Software impact (see the TODO in `TAPJIG.md`)

- Split the engine into a package and add the fixture-profile lookup between
  routine signals and the jig's line protocol.
- Jig line protocol grows from a handful of named nodes to generic
  commands over named resources (`ADC <resource>`, `DIO <resource> <mode>
  <value>`, `RAIL <name> <on|off> <limit>`, `BUS ...`), with the jig
  profile saying which exist. A routine that needs something the connected
  jig or fixture lacks is rejected before the run starts.
- Product-specific DUT communication (feeder RS-485 frames, mainboard TBD)
  stays a per-product plugin kept in the repo, not on the SMB share.
- Auto-select: the fixture ID picks the product when only one product matches
  that fixture.

## Decisions and findings from the follow-up discussion

**Parts chosen so far:** MCP23017 (I/O expanders), ADS1115 (ADC),
CA-IS3092VW (isolated RS-485), CAN as an option only, "decent" relays for the
power stages and miniature relays for detection (so the 10 kOhm cold-resistance
sniff can be switched out and never loads the rail afterwards), 2 or 3 card-edge
connectors of 60 pins each.

### Is the 32u4 enough? No

26 usable pins, one UART, one I2C, one SPI, 2.5 KB RAM and 8-bit 16 MHz. It
cannot host two RS-485 ports, CAN, several I2C buses and a block framework, and
it has no spare pins for the budget above. Move to a bigger MCU. Two sensible
choices:

| | RP2350 (e.g. RP2350B, 48 GPIO) | STM32G474 (or a similar G4/H5) |
|---|---|---|
| Strength | **PIO state machines can make an encoder, capture, UART, SPI or custom serial on almost any pin**: matches "pins P122/P123 are A and B, set up an encoder" best | real hardware encoder interface, capture and PWM on timers; built-in CAN-FD; many 5 V-tolerant pins |
| Weakness | CAN needs an external controller (e.g. MCP2518FD over SPI); 3.3 V pins; 48 GPIO | each peripheral only works on its alternate-function pins, so "any block on any pin" is limited by the pin mux |
| Pick if | arbitrary pin-to-function mapping matters most | you want the most robust hardware blocks and CAN on-chip |

Either way, every connector line needs level translation to the fixture's
logic reference (Vio), so MCU pins do not touch the pogo side directly. A small
FPGA would give fully arbitrary routing, but it is overkill for now.

### Expanders and ADC: what they can and cannot do

- **MCP23017 pins are slow-class**: an I2C transaction per change (about
  100 us at 1 MHz), no timers, no peripherals. Use them for switches, reset
  forcing, level reads, relay drivers and enables. **Encoders, PWM, capture
  and UART/SPI blocks must sit on MCU pins.** The pin table therefore carries a
  capability class (`fast` / `slow`) and the config tool refuses an
  impossible assignment.
- Outputs are push-pull only; emulate "open-drain low" by switching the pin
  between input and driven-low. Run each expander at the bank's Vio. Eight
  addresses per bus (128 pins), so two or three buses leave plenty of room.
- **ADS1115**: 16 bit but slow (860 SPS per device, one conversion at a time),
  four addresses per bus. Fine for DC rails and LDR levels, not for waveforms.
  Its inputs must never exceed its supply, so scaling and clamping belong on
  the fixture (or a protected input stage on the base).
- **Relays**: allow 5-10 ms settle after any relay change, drive coils through
  low-side drivers with flyback protection, and add a "rail off but a downstream
  node still reads voltage" check to catch a welded power relay.
- **CA-IS3092VW** gives isolated RS-485; its integrated isolated supply is
  limited, so budget it per port. The same vendor family has isolated CAN
  transceivers for the optional CAN port.

### Blocks (the "P122 and P123 are an encoder" idea)

A **block** is a typed peripheral instance bound to named pins, created at run
time from the fixture profile. The host never writes to a pin directly for
these; it creates a block and talks to it.

```json
{ "blocks": [
  { "id": "enc_m1",  "type": "encoder",  "pins": {"A": "P122", "B": "P123"}, "counts_per_rev": 400 },
  { "id": "servo0",  "type": "servo",    "pins": {"OUT": "P130"} },
  { "id": "sw1",     "type": "gpio_od_low", "pins": {"OUT": "P207"} },
  { "id": "bus0",    "type": "rs485",    "pins": {"TX": "P010", "RX": "P011", "DE": "P012"}, "baud": 9600 },
  { "id": "fb",      "type": "adc",      "pins": {"IN": "A00"}, "range": "2.5V", "scale": 1.0 }
] }
```

- Block types (initial set to implement, extensible): `gpio_in`, `gpio_out`,
  `gpio_od_low`, `pwm`, `servo`, `encoder`, `freq_counter`/`capture`, `uart`,
  `rs485`, `can`, `spi_dev`, `i2c_dev`, `adc`, `dac`, `relay`, `rail`,
  `pixel` (addressable LED), and later whatever a product needs.
- Firmware keeps a **block registry** (one driver per type). The jig profile
  lists which types it supports and which pins are `fast` or `slow`. The host
  validates the whole fixture profile against that before a run, and the
  protocol is generic: `BLOCK NEW <id> <type> <pin=...> <param=...>`,
  `BLOCK SET`, `BLOCK GET`, `BLOCK FREE`.
- Pin names are global (`P000..` for MCU pins, `P2xx` for expander pins, `A..`
  for analog, rails by name), so a fixture profile is the only place that
  knows how a product is wired.
- The routine still talks about **signals** and a block id, never raw pins.

### Connectors: 2 or 3 x 60-pin card edge

Count the budget first: 64 digital + 16 analog + 4 AO + buses + programming
lines + a ground per few signals is already about 150-180 contacts, so plan for
**3 connectors**:

1. **Power and sense**: rails, Kelvin sense, many grounds. Card-edge contacts
   carry only a few amps each (check the connector datasheet and derate), so a
   multi-amp 24 V rail needs several contacts in parallel per leg, or a
   separate power connector. Keep it physically apart from the analog.
2. **Digital**: expander and MCU digital lines, interleaved with grounds.
3. **Analog, buses and programming**: ADC inputs, DAC, RS-485/CAN/UART, I2C,
   SPI, SWD, ISP, fixture ID EEPROM, interlock.

If three keyed edges plus alignment are too awkward mechanically, that is the
point to prefer the backplane-with-cards option.
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

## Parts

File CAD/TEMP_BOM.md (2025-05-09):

# OrionPnP Bill of Materials (BOM)

> This document outlines the complete bill of materials for building an OrionPnP machine.  
Each section describes the components required for different subsystems of the machine.  
PCB-specific components are listed separately in each board's repository folder.

---

## 📦 Mechanical

This section includes fasteners, aluminum extrusions, linear rails, and all structural hardware required for the main chassis and gantry assembly. It also has motion components, belts, steppers and such.

### Frame Structure

Price for mech. parts: € 38,56 

| Part ID | Part description | Qty. | Price | Total  | Source | Code | Notes  |
| --- | --- | --- | --- | --- | ----- | --- | --- |
| 2020_478 | 2020 profile – Length 478mm | 1 | €0,8560 | €0,86 | JLCMC | TXCJ-H7-6-2020-L478 | X axis |
| 2020_450 | 2020 profile – Length 450mm | 4 | €0,8062 | €3,22 | JLCMC | TXCJ-H7-6-2020-L450 | Y body |
| 2020_435 | 2020 profile – Length 435mm | 6 | €0,7792 | €4,68 | JLCMC | TXCJ-H7-6-2020-L435 | X body |
| 2020_250 | 2020 profile – Length 250mm | 4 | €0,4678 | €1,87 | JLCMC | TXCJ-H7-6-2020-L250 | Vertical / z axis |
| Bracket_2020 | 2020 profile angle bracket | 30 | €0,0671 | €2,01 | JLCMC | TPDB-206-2020 |  |
| Tnut_M3 | M3 drop-in T-nut | 300 | €0,0090 | €2,70 | JLCMC | TPAA-N-6-M3 | 100pcs+ |
| Tnut_M5 | M5 drop-in T-nut | 300 | €0,0055 | €1,65 | JLCMC | TPAA-N-6-M5 | 100pcs+ |
| BallNut_M3 | M3 spring-loaded ball nut | 100 | €0,0288 | €2,88 | JLCMC | TPAB-N-6-M3 | 100pcs+ |
| BallNut_M4 | M4 spring-loaded ball nut | 50 | €0,0294 | €1,47 | JLCMC | TPAB-N-6-M4 | 50pcs+ |
| BallNut_M5 | M5 spring-loaded ball nut | 100 | €0,0288 | €2,88 | JLCMC | TPAB-N-6-M5 | 100pcs+ |
| HSCS_3x6 | Hex socket cap screw – M3x6mm | 100 | €0,0037 | €0,37 | JLCMC | EDLA-S1-M3-L6 | 100pcs+ |
| HSCS_3x10 | Hex socket cap screw – M3x10mm | 100 | €0,0047 | €0,47 | JLCMC | EDLA-S1-M3-L10 | 100pcs+ |
| HSCS_3x12 | Hex socket cap screw – M3x12mm | 100 | €0,0051 | €0,51 | JLCMC | EDLA-S1-M3-L12 | 100pcs+ |
| HSCS_3x18 | Hex socket cap screw – M3x18mm | 100 | €0,0068 | €0,68 | JLCMC | EDLA-S1-M3-L18 | 100pcs+ |
| HSCS_3x25 | Hex socket cap screw – M3x25mm | 100 | €0,0085 | €0,85 | JLCMC | EDLA-S1-M3-L25 | 100pcs+ |
| HSBH_3x6 | Hex socket ball head screw – M3x6mm  | 100 | €0,0031 | €0,31 | JLCMC | EDLG-S1-M3-L6 | 100pcs+ |
| HSBH_3x10 | Hex socket ball head screw – M3x10mm | 100 | €0,0043 | €0,43 | JLCMC | EDLG-S1-M3-L10 | 100pcs+ |
| HSBH_3x12 | Hex socket ball head screw – M3x12mm | 100 | €0,0042 | €0,42 | JLCMC | EDLG-S1-M3-L12 | 100pcs+ |
| HSBH_3x18 | Hex socket ball head screw – M3x18mm | 100 | €0,0056 | €0,56 | JLCMC | EDLG-S1-M3-L18 | 100pcs+ |
| HSBH_3x25 | Hex socket ball head screw – M3x25mm | 100 | €0,0073 | €0,73 | JLCMC | EDLG-S1-M3-L25 | 100pcs+ |
| HSCS_4x10 | Hex socket cap screw – M4x10mm | 100 | €0,0074 | €0,74 | JLCMC | EDLA-S1-M4-L10 | 100pcs+ |
| HSCS_5x10 | Hex socket cap screw – M5x10mm | 100 | €0,0105 | €1,05 | JLCMC | EDLA-S1-M5-L10 | 100pcs+ |
| HSCS_5x20 | Hex socket cap screw – M5x20mm | 50 | €0,0146 | €0,73 | JLCMC | EDLA-S1-M5-L20 | 50pcs+ |
| Nut_Lock_M5 | M5 locking nylock nut | 50 | €0,0116 | €0,58 | JLCMC | EMLC-C2-Y-M5 | 50pcs+ |
| WASH_M3 | M3 Washer – Standard | 100 | €0,0011 | €0,11 | JLCMC | EPDA-S1W-B-3 | 100pcs+ |
| WASH_M4_W | M4 washer – Wide | 50 | €0,0030 | €0,15 | JLCMC | EPDA-S1W-K-4 | 50pcs+ |
| WASH_M5 | M5 Washer – Standard | 100 | €0,0019 | €0,19 | JLCMC | EPDA-S1W-B-5 | 100pcs+ |
| M3_Insert | M3 threaded insert – Standard | 100 | €0,0546 | €5,46 | Ali | [Link](https://www.aliexpress.com/item/1005003582355741.html?spm=a2g0o.order_list.order_list_main.160.79341802HGwDOj) | M3 – OD4.5 – 4mm |
| M5_Insert | M5 threaded insert – Standard | 20 | €0,0680 | €1,36 | Ali | [Link](https://www.aliexpress.com/item/1005003582355741.html?spm=a2g0o.order_list.order_list_main.160.79341802HGwDOj) | M5 – OD7.5 – 5mm |

---

## ⚙️ Motion

All the parts needed for the motion system are in this list, the total cost for these is €232,97

| Part ID | Part description | Qty. | Price | Total  | Source | Code | Notes  |
| --- | --- | --- | --- | --- | ----- | --- | --- |
| Rail_400mm | MGN12H Rail – 400mm | 3 | €25,9800 | €77,94 | Amazon | B08G1GVK7Q | 400mm |
| Rail_100mm | MGN9H Rail – 100mm | 2 | €17,7900 | €35,58 | Amazon | B09FSG4KG3 | 100mm |
| Chain_Wide | 18x37mm cable chain | 2 | €9,2900 | €18,58 | Ali | [Link](https://www.aliexpress.com/item/32852122851.html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) | 18x37mm radius 38mm |
| Idler_6B5_GT2 | Toothed GT2 idler for 6mm belt – 5mm bore | 7 | €2,6690 | €18,68 | Ali | [Link](https://www.aliexpress.com/item/1005004957508089.html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!€%203%2C43!€%203%2C43!!!3.78!3.78!@210390b817465199995396778e3863!12000031185339695!sh!IT!910753856!X) | Select 10pcs, 5mm bore |
| Idler_6B5_Smooth | Smooth idler for 6mm belt – 5mm bore | 2 | €2,6790 | €5,36 | Ali | [Link](https://www.aliexpress.com/item/1005004957508089.html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!€%203%2C43!€%203%2C43!!!3.78!3.78!@210390b817465199995396778e3863!12000031185339695!sh!IT!910753856!X) | Select 10pcs, 5mm bore |
| Pulley_6B5_20T | 20T pulley for GT2 belts – 5mm bore | 4 | €3,0650 | €12,26 | Ali | [Link](https://www.aliexpress.com/item/32816906105.html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!€%203%2C34!€%203%2C34!!!3.68!3.68!@210390b817465199995396778e3863!66526242417!sh!IT!910753856!X) | Select 6pcs, 5mm bore |
| GT2_Belt | Gates GT2 belt – 6mm | 1 | €18,5900 | €18,59 | Ali | [Link](https://www.aliexpress.com/item/1005006507781085.html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,scm-url:1007.40050.354490.0,pvid:0f58cc73-9ff9-47ea-8e2f-682e2c40a00d,tpp_buckets:668%232846%238107%231934&pdp_ext_f=%7B%22order%22%3A%22953%22%2C%22eval%22%3A%221%22%2C%22sceneId%22%3A%2230050%22%7D&pdp_npi=4%40dis%21EUR%218.19%218.19%21%21%219.03%219.03%21%402103894417465200153966833ea9ff%2112000037754698142%21rec%21IT%21910753856%21X&utparam-url=scene%3ApcDetailTopMoreOtherSeller%7Cquery_from%3A) | Select 4m |
| Stepper_17_2A | Nema17 stepper – 2A current – PCB plugs | 3 | €11,5300 | €34,59 | Ali | [Link](https://www.aliexpress.com/item/1005004731197516.html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,scm-url:1007.40050.354490.0,pvid:6313c9a0-307d-4983-9518-3773d1680322,tpp_buckets:668%232846%238107%231934&pdp_ext_f=%7B%22order%22%3A%22338%22%2C%22eval%22%3A%221%22%2C%22sceneId%22%3A%2230050%22%7D&pdp_npi=4@dis!EUR!23.55!17.19!!!25.97!18.96!@210384cc17465239866344829ebe6b!12000030302442011!rec!IT!910753856!X&utparam-url=scene%3ApcDetailTopMoreOtherSeller%7Cquery_from%3A) | Select 3pcs |
| Stepper_17_1A | Nema17 stepper – 2A current – wire – pancake | 1 | €11,3900 | €11,39 | Ali | [Link](https://www.aliexpress.com/item/32585429251.html?pdp_npi=4@dis!EUR!€%2011%2C39!€%2011%2C39!!!12.56!12.56!@211b813f17465242330216289e1c93!65367836295!sh!IT!910753856!X&spm=a2g0o.store_pc_allItems_or_groupList.new_all_items_2007599132608.32585429251) |  |

---

## 🔌 Electronics

This section covers off-the-shelf electronic modules and wiring for the system.  
PCBs such as the mainboard and host/feeder boards have **their own BOMs in their project folders**.
The cost of the electronics is of €322,70

| Part ID | Part description | Qty. | Price | Total  | Source | Code | Notes  |
| --- | --- | --- | --- | --- | ----- | --- | --- |
| LRS-350-24 | Meanwell LRS-350-24 Switching PSU – 350W – 24V | 1 | €49,3900 | €49,39 | Ali | [Link](https://www.aliexpress.com/item/32857859551.html?pdp_npi=4@dis!EUR!€%2053%2C68!€%2049%2C39!!!59.20!54.47!@211b618e17465226796515990ef6ec!65365302140!sh!IT!910753856!X&spm=a2g0o.store_pc_allItems_or_groupList.new_all_items_2007447399652.32857859551) | 350W – 24V |
| Orion_Core | Orion core v0.2a mainboard | 1 | €175,0000 | €175,00 | JLCPCB | n/a | Indicative pricing |
| Orion_Light | Orion camera light – 12V | 2 | €12,0000 | €24,00 | JLCPCB | n/a | Indicative pricing |
| IEC_Switch | IEC socket with integrated switch and fuse | 1 | €12,1300 | €12,13 | LCSC | C17570428 |  |
| USB_Cam | ELP USB camera | 2 | €31,0900 | €62,18 | Ali | [Link](https://www.aliexpress.com/item/32974277512.html?spm=a2g0o.order_list.order_list_main.563.79341802HGwDOj) | 1x 3,6mm – 1x 8mm |
---

## 🤖 Feeders

Base materials and non-electrical parts for building tape feeders. The cost each is around 10€

| Part ID | Part description | Qty. | Price | Total  | Source | Code | Notes  |
| --- | --- | --- | --- | --- | ----- | --- | --- |
| Feeder_PCB | OrionPnP Feeder V0.2a | 1  | €9,0000 | €45,00 | JLCPCB | n/a | Indicative pricing |
| M2_Insert | M2 threaded insert | 10 | €0,0490 | €2,45 | Ali | [Link](https://www.aliexpress.com/item/1005003582355741.html?spm=a2g0o.order_list.order_list_main.160.79341802HGwDOj) | M2 – OD3.5 – 3,5mm |
| M2_Low_4mm | Low profile M2x4mm torx screw | 8  | €0,0462 | €1,85 | Ali | [Link](https://www.aliexpress.com/item/1005005070119421.html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) | M2 – 4mm |
| M2_Low_6mm | Low profile M2x6mm torx screw | 2  | €0,0484 | €0,48 | Ali | [Link](https://www.aliexpress.com/item/1005005070119421.html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) | M2 – 6mm |

For electronics and firmware, see the [Feeder Design](../../wiki/Feeder-Design) and [Command Reference](../../wiki/OrionProtocol) pages.

---

## 🔄 Pneumatics

Components related to vacuum generation and switching.

| Part ID | Part description | Qty. | Price | Total  | Source | Code | Notes  |
| --- | --- | --- | --- | --- | ----- | --- | --- |
| VAC_12V_Pump | 12V vacuum pump | 1 | €8,3900 | €8,39 | Ali | [Link](https://www.aliexpress.com/item/1005007455425755.html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) | 12V |
| Solenoid_12V | 12V solenoid | 4 | €7,7900 | €31,16 | Ali | [Link](https://www.aliexpress.com/item/1005005295947399.html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) | 12V – PC4 fittings |
| Head_pnp | Pick and place head – Motor + fittings + nozzle | 2 | €43,4900 | €86,98 | Ali | [Link](https://www.aliexpress.com/item/1005004594670502.html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) | Select Nema8 + nozzle |
| Tubing | 6x4mm tubing for air | 1 | €3,6400 | €3,64 | Ali | [Link](https://www.aliexpress.com/item/1005004003104058.html?spm=a2g0o.order_list.order_list_main.574.79341802HGwDOj) | 6x4 |

---

## 🧩 3D Printed Parts

This section will contain all printed components, organized by function.  
All models are included in the 'OrionPnP' and 'Feeders' folders. For the assembly instructions visit the [Build Your Own](../../wiki/Build-Your-Own) page.

---

## Notes

- For recommended vendors, quantity breakdowns, and part numbers, see the full CSV or spreadsheet BOM.
- For any PCB-specific components, refer to the BOM in that board’s GitHub subfolder.

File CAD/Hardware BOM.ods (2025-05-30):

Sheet: Hardware + non-printed parts
Code | Description | Amount | Price | Total | Source | Part n./ASIN/Link | Notes | Sourced?
MECHANICAL (Profiles, screws…) |  |  |  |  |  | Price for mech. parts | € 41,70
2020_478 | 2020 profile – Length 478mm | 1 | € 0,8560 | € 0,86 | JLCMC | TXCJ-H7-6-2020-L478 | X axis |  | € 0,86
2020_450 | 2020 profile – Length 550mm | 4 | € 0,9833 | € 3,93 | JLCMC | TXCJ-H7-6-2020-L550 | Y body |  | € 3,93
2020_435 | 2020 profile – Length 435mm | 6 | € 0,7792 | € 4,68 | JLCMC | TXCJ-H7-6-2020-L435 | X body |  | € 4,68
2020_250 | 2020 profile – Length 250mm | 4 | € 0,4678 | € 1,87 | JLCMC | TXCJ-H7-6-2020-L250 | Vertical / z axis |  | € 1,87
Bracket_2020 | 2020 profile angle bracket | 30 | € 0,0671 | € 2,01 | JLCMC | TPDB-206-2020 |  |  | € 2,01
Tnut_M3 | M3 drop-in T-nut | 250 | € 0,0090 | € 2,25 | JLCMC | TPAA-N-6-M3 | 100pcs+ |  | € 2,25
Tnut_M5 | M5 drop-in T-nut | 300 | € 0,0055 | € 1,65 | JLCMC | TPAA-N-6-M5 | 100pcs+ |  | € 1,65
BallNut_M3 | M3 spring-loaded ball nut | 150 | € 0,0288 | € 4,32 | JLCMC | TPAB-N-6-M3 | 100pcs+ |  | € 4,32
BallNut_M4 | M4 spring-loaded ball nut | 50 | € 0,0294 | € 1,47 | JLCMC | TPAB-N-6-M4 | 50pcs+ |  | € 1,47
BallNut_M5 | M5 spring-loaded ball nut | 150 | € 0,0288 | € 4,32 | JLCMC | TPAB-N-6-M5 | 100pcs+ |  | € 4,32
HSCS_3x6 | Hex socket cap screw – M3x6mm | 100 | € 0,0037 | € 0,37 | JLCMC | EDLA-S1-M3-L6 | 100pcs+ |  | € 0,37
HSCS_3x10 | Hex socket cap screw – M3x10mm | 100 | € 0,0047 | € 0,47 | JLCMC | EDLA-S1-M3-L10 | 100pcs+ |  | € 0,47
HSCS_3x12 | Hex socket cap screw – M3x12mm | 100 | € 0,0051 | € 0,51 | JLCMC | EDLA-S1-M3-L12 | 100pcs+ |  | € 0,51
HSCS_3x18 | Hex socket cap screw – M3x18mm | 100 | € 0,0068 | € 0,68 | JLCMC | EDLA-S1-M3-L18 | 100pcs+ |  | € 0,68
HSCS_3x25 | Hex socket cap screw – M3x25mm | 100 | € 0,0085 | € 0,85 | JLCMC | EDLA-S1-M3-L25 | 100pcs+ |  | € 0,85
HSBH_3x6 | Hex socket ball head screw – M3x6mm | 100 | € 0,0031 | € 0,31 | JLCMC | EDLG-S1-M3-L6 | 100pcs+ |  | € 0,31
HSBH_3x10 | Hex socket ball head screw – M3x10mm | 100 | € 0,0043 | € 0,43 | JLCMC | EDLG-S1-M3-L10 | 100pcs+ |  | € 0,43
HSBH_3x12 | Hex socket ball head screw – M3x12mm | 100 | € 0,0042 | € 0,42 | JLCMC | EDLG-S1-M3-L12 | 100pcs+ |  | € 0,42
HSBH_3x18 | Hex socket ball head screw – M3x18mm | 100 | € 0,0056 | € 0,56 | JLCMC | EDLG-S1-M3-L18 | 100pcs+ |  | € 0,56
HSBH_3x25 | Hex socket ball head screw – M3x25mm | 100 | € 0,0073 | € 0,73 | JLCMC | EDLG-S1-M3-L25 | 100pcs+ |  | € 0,73
HSCS_4x10 | Hex socket cap screw – M4x10mm | 100 | € 0,0074 | € 0,74 | JLCMC | EDLA-S1-M4-L10 | 100pcs+ |  | € 0,74
HSCS_5x10 | Hex socket cap screw – M5x10mm | 100 | € 0,0105 | € 1,05 | JLCMC | EDLA-S1-M5-L10 | 100pcs+ |  | € 1,05
HSCS_5x20 | Hex socket cap screw – M5x20mm | 50 | € 0,0146 | € 0,73 | JLCMC | EDLA-S1-M5-L20 | 50pcs+ |  | € 0,73
Nut_Lock_M5 | M5 locking nylock nut | 50 | € 0,0116 | € 0,58 | JLCMC | EMLC-C2-Y-M5 | 50pcs+ |  | € 0,58
WASH_M3 | M3 Washer – Standard | 100 | € 0,0011 | € 0,11 | JLCMC | EPDA-S1W-B-3 | 100pcs+ |  | € 0,11
WASH_M4_W | M4 washer – Wide | 50 | € 0,0030 | € 0,15 | JLCMC | EPDA-S1W-K-4 | 50pcs+ |  | € 0,15
WASH_M5 | M5 Washer – Standard | 100 | € 0,0019 | € 0,19 | JLCMC | EPDA-S1W-B-5 | 100pcs+ |  | € 0,19
M3_Insert | M3 threaded insert – Standard | 100 | € 0,0546 | € 5,46 | Ali | Link (https://www.aliexpress.com/item/1005003582355741.html) | M3 – OD4.5 – 4mm |  | € 5,46
M5_Insert | M5 threaded insert – Standard | 20 | € 0,0680 | € 1,36 | Ali | Link (https://www.aliexpress.com/item/1005003582355741.html) | M5 – OD7.5 – 5mm |  | € 1,36
MOTION (Linear rails, steppers, pulleys...) |  |  |  |  |  | Price for motion parts | € 232,97
Rail_400mm | MGN12H Rail – 400mm | 3 | € 25,9800 | € 77,94 | Amazon | B08G1GVK7Q | 400mm |  | € 77,94
Rail_100mm | MGN9H Rail – 100mm | 2 | € 17,7900 | € 35,58 | Amazon | B09FSG4KG3 | 100mm |  | € 35,58
Chain_Wide | 18x37mm cable chain | 2 | € 9,2900 | € 18,58 | Ali | Link (https://www.aliexpress.com/item/32852122851.html?mp=1) | 18x37mm radius 38mm |  | € 18,58
Idler_6B5_GT2 | Toothed GT2 idler for 6mm belt – 5mm bore | 7 | € 2,6690 | € 18,68 | Ali | Link (https://www.aliexpress.com/item/1005004957508089.html) | Select 10pcs, 5mm bore | y | 0
Idler_6B5_Smooth | Smooth idler for 6mm belt – 5mm bore | 2 | € 2,6790 | € 5,36 | Ali | Link (https://www.aliexpress.com/item/1005004957508089.html) | Select 10pcs, 5mm bore | y | 0
Pulley_6B5_20T | 20T pulley for GT2 belts – 5mm bore | 4 | € 3,0650 | € 12,26 | Ali | Link (https://www.aliexpress.com/item/32816906105.html) | Select 6pcs, 5mm bore | y | 0
GT2_Belt | Gates GT2 belt – 6mm | 1 | € 18,5900 | € 18,59 | Ali | Link (https://www.aliexpress.com/item/1005006507781085.html?scm_id=1007.40050.354490.0&scm-url=1007.40050.354490.0) | Select 4m |  | € 18,59
Stepper_17_2A | Nema17 stepper – 2A current – PCB plugs | 3 | € 11,5300 | € 34,59 | Ali | Link (https://www.aliexpress.com/item/1005004731197516.html?scm_id=1007.40050.354490.0&scm-url=1007.40050.354490.0) | Select 3pcs | y | 0
Stepper_17_1A | Nema17 stepper – 2A current – wire – pancake | 1 | € 11,3900 | € 11,39 | Ali | Link (https://www.aliexpress.com/item/32585429251.html) |  | y | 0
ELECTRONICS (PCBs, camera, PSU…) |  |  |  |  |  | Price for electroncis | € 355,28
LRS-350-24 | Meanwell LRS-350-24 Switching PSU – 350W – 24V | 1 | € 49,3900 | € 49,39 | Ali | Link (https://www.aliexpress.com/item/32857859551.html) | 350W – 24V | y | 0
Orion_Core | Orion core v0.2a mainboard | 1 | € 175,0000 | € 175,00 | JLCPCB | n/a | Indicative pricing | y | 0
Orion_Light | Orion camera light – 12V | 2 | € 12,0000 | € 24,00 | JLCPCB | n/a | Indicative pricing | y | € 0,00
IEC_Switch | IEC socket with integrated switch and fuse | 1 | € 12,1300 | € 12,13 | LCSC | C17570428 |  |  | € 12,13
USB_Cam | ELP USB camera | 2 | € 31,0900 | € 62,18 | Ali | Link (https://www.aliexpress.com/item/32974277512.html) | 1x 3,6mm – 1x 8mm | y | 0
Cable_USB | Shielded Twisted 4 conductor cable | 1 | € 10,6900 | € 10,69 | Ali | Link (https://www.aliexpress.com/item/1005002726060505.html) | Select 4 cores 5mt | y | 0
Cable_PTFE | PTFE cable for harness | 1 | € 21,8900 | € 21,89 | Ali | Link (https://www.aliexpress.com/item/1005008237966380.html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) | Select 22AWG 25mt |  | € 21,89
Housing_Stepper | Stepper cable XH housing | 100 | € 0,0047 | € 0,47 | LCSC | C15929 | 100 MOQ |  | € 0,47
Contact_Stepper | Contact for XH housings | 100 | € 0,0097 | € 0,97 | LCSC | C140573 | 100 MOQ |  | € 0,97
Cable_Harness | Cable for harness – Helukabel SUPERTRONIC 4x0,32 | 25 | € 0,9800 | € 24,50 | TME | STR-PVC4X0.34 | Price for 25m+ |  | € 24,50
FEEDERS (PCBs, fasteners…) |  |  |  |  |  | N° of feeders to make: | 5
Feeder_PCB | OrionPnP Feeder V0.2a | 1 | € 9,0000 | € 45,00 | JLCPCB | n/a | Indicative pricing |  | € 45,00
M2_Insert | M2 threaded insert | 10 | € 0,0490 | € 2,45 | Ali | Link (https://www.aliexpress.com/item/1005003582355741.html) | M2 – OD3.5 – 3,5mm |  | € 2,45
M2_Low_4mm | Low profile M2x4mm torx screw | 8 | € 0,0462 | € 1,85 | Ali | Link (https://www.aliexpress.com/item/1005005070119421.html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) | M2 – 4mm |  | € 1,85
M2_Low_6mm | Low profile M2x6mm torx screw | 2 | € 0,0484 | € 0,48 | Ali | Link (https://www.aliexpress.com/item/1005005070119421.html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) | M2 – 6mm |  | € 0,48
N20_Motor | Miniature GA12-N20 motor | 2 | € 3,4100 | € 34,10 | Ali | Link (https://www.aliexpress.com/item/1005005699205905.html?mp=1) | Select 6V 50RPM |  | € 34,10
PNEUMATICS (Pump, solenoids…) |  |  |  |  |  | Price for pneumatics | € 130,17
VAC_12V_Pump | 12V vacuum pump | 1 | € 8,3900 | € 8,39 | Ali | Link (https://www.aliexpress.com/item/1005007455425755.html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) | 12V | y | 0
Solenoid_12V | 12V solenoid | 4 | € 7,7900 | € 31,16 | Ali | Link (https://www.aliexpress.com/item/1005005295947399.html?mp=1) | 12V – PC4 fittings | y | 0
Head_pnp | Pick and place head – Motor + fittings + nozzle | 2 | € 43,4900 | € 86,98 | Ali | Link (https://www.aliexpress.com/item/1005004594670502.html?mp=1) | Select Nema8 + nozzle | y | 0
Tubing | 6x4mm tubing for air | 1 | € 3,6400 | € 3,64 | Ali | Link (https://www.aliexpress.com/item/1005004003104058.html) | 6x4 | y | 0
 | Cost of OrionPnP with feeders (excluding printed parts) |  |  | € 871,30 |  |  | REMAINING | 337,5906

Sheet: Printed parts
Filename | Description | Amount | Material | Color | Printed
Toolhead
Head_Baseplate | Baseplate to attach all components | 1 | * | *
Head_rear_cover | Rear cover, also has belt loops | 1 | * | *
Head_camera_separator | Separates the camera from the LED light | 1 | * | *
Head_light_holder_ring | Print in black, avoids lightbleed on the camera from LEDs | 1 | * | Black
Head_light_holder | Used to mount the light to the camera. Print in black to help vision | 1 | * | Black
Head_diffuser | Print thin in white, used to diffuse light. 1 or 2 layer, no more | 1 | * | White
Head_cable_bridge | Directs the cables from the camera above the gear | 1 | * | *
Head_spur_gear | Spur gear for z axis movement | 1 | * | *
Head_nozzle_R_holder | To hold the motor for the right nozzle | 1 | * | *
Head_nozzle_L_holder | To hold the motor for the left nozzle | 1 | * | *
Head_Chain_mount | Adapter to mount the cable chain going to the head | 1 | * | *
Y Axis
Y_corner_idler_holder_L | Corner holder for left idler on y axis | 1 | * | *
Y_corner_idler_holder_R | Corner holder for right idler on y axis | 1 | * | *
Y_motor_bracket | Bracket to hold the motor | 2 | * | *
Y_motor_mount_R | Right side motor mount | 1 | * | *
Y_motor_mount_L | Left side motor mount | 1 | * | *
Y_Stopper | Stopper for sensorless homing. Replaceable if endstop homing is implemented | 2 | * | *
X Axis
X_Motor_carriage | Connects X beam to the y axis on the left side | 1 | ABS/ASA | /
X_Motor_mount | Connects X motor to the carriage and provides cable chain mounting | 1 | ABS/ASA | /
X_Tensioner_carriage | Connects X beam to the y axis on the right side | 1 | ABS/ASA | /
X_Tensioner | Tensioner for the X axis belt | 1 | ABS/ASA | /
X_Tensioner_plate | Small plate to hold the belt in the tensioner. | 2 | ABS/ASA | /
X_Chain_mount | Adapter to mount the cable chain going to the head to the x motor mount | 1 | ABS/ASA | /

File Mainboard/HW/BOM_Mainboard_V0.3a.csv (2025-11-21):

No. | Quantity | Comment | Designator | Footprint | Value | Manufacturer Part | Manufacturer | Supplier Part | Supplier
1 | 6 | 14pF | C1,C2,C103,C104,C144,C145 | C0402 | 14pF
2 | 20 | 100nF | C4,C5,C8,C12,C75,C76,C105,C106,C107,C108,C109,C116,C118,C119,C121,C124,C131,C141,C142,C143 | C0402 | 100nF |  |  | C1525
3 | 2 | 22u | C9,C10 | C0603 | 22u
4 | 1 | 220p | C11 | C0603 | 220p
5 | 2 | 10u | C13,C101 | C0603 | 10u
6 | 6 | 22nF 50V | C14,C21,C28,C35,C42,C49 | C0603 | 22nF 50V
7 | 18 | 100nF 50V | C15,C16,C17,C22,C23,C24,C29,C30,C31,C36,C37,C38,C43,C44,C45,C50,C51,C52 | C0603 | 100nF 50V
8 | 6 | 100uF | C18,C25,C32,C39,C46,C53 | CAP-SMD_BD8.0-L8.3-W8.3-FD | 100uF | EEEFP1H101AP | PANASONIC(松下) | C401753 | LCSC
9 | 7 | 100nF | C19,C26,C33,C40,C47,C54,C102 | C0603 | 100nF
10 | 8 | 2u2 6.3V | C20,C27,C34,C41,C48,C55,C85,C86 | C0603 | 2u2 6.3V
11 | 12 | 4u7 35v | C56,C57,C58,C59,C60,C61,C62,C63,C64,C65,C66,C67 | C0603 | 4u7 35v
12 | 21 | 100nF | C87,C88,C89,C90,C91,C92,C93,C94,C95,C96,C97,C98,C99,C100,C123,C139,C140,C147,C148,C149,C150 | C0402 | 100nF | CL05B104KO5NNNC | SAMSUNG(三星) | C1525 | LCSC
13 | 2 | 470pF | C125,C132 | C0402 | 470pF | GRM1555C1H471JA01D | muRata(村田) | C76971 | LCSC
14 | 6 | 10uF | C126,C127,C129,C133,C134,C136 | C1206 | 10uF | CL31A106KBHNNNE | SAMSUNG(三星) | C13585 | LCSC
15 | 2 | 47uF | C128,C135 | C1210 | 47uF | GRM32ER61C476KE15L | muRata(村田) | C77101 | LCSC
16 | 2 | 4.7uF | C130,C137 | C0603 | 4.7uF | CL10A475KA8NQNC | SAMSUNG(三星) | C69335 | LCSC
17 | 2 | 1uF | C138,C146 | C0402 | 1uF | CL05A105KA5NQNC | SAMSUNG(三星) | C52923 | LCSC
18 | 4 | 1751264 | CN1,CN2,CN3,CN4 | CONN-TH_MKDS1-4-3.5 |  | 1751264 | Phoenix Contact(菲尼克斯) | C99845 | LCSC
19 | 1 | 20021521-00010T1LF | CN5 | IDC-SMD_10P-P1.27_X1270WVS-2X05B-6TV01 |  | 20021521-00010T1LF | Amphenol | C2972785 | LCSC
20 | 1 | 2510-4A | CN6 | CONN-TH_4P-P2.54_CAX_2510-4A |  | 2510-4A | CAX(创都) | C2847671 | LCSC
21 | 5 | USBLC6-2P6 | D1,D6,D7,D13,D14 | SOT-666-6_L1.6-W1.2-P0.50-LS1.6-BR |  | USBLC6-2P6 | ST(意法半导体) | C15999 | LCSC
22 | 5 | 1N5819HW-7-F | D8,D9,D10,D11,D12 | SOD-123_L2.7-W1.6-LS3.7-RD |  | 1N5819HW-7-F | DIODES(美台) | C82544 | LCSC
23 | 3 | XF-508P-B-B | F1,F2,F3 | FUSE-TH_4P-L16.0-W6.7 |  | XF-508P-B-B | XFCN(兴飞) | C19727305 | LCSC
24 | 2 | HDR-M_2.54_1x3P | H1,H2 | HDR-TH_3P-P2.54-V-M
25 | 1 | HDR-M_2.54_2x2 | H3 | HDR-TH_4P-P2.54-V-M-R2-C2-S2.54-1
26 | 1 | 3.3uH | L1 | IND-SMD_L7.0-W6.6 | 3.3uH | SL0630-3R3M | 台湾陆海 | C22463820 | LCSC
27 | 6 | NCD0805R1 | LED1,LED2,LED3,LED4,LED5,LED6 | LED0805-R-RD |  | NCD0805R1 | 国星光电 | C84256 | LCSC
28 | 2 | AO3400A | Q1,Q2 | SOT-23-3_L2.9-W1.3-P1.90-LS2.4-BR |  | AO3400A | UMW(友台半导体) | C347475 | LCSC
29 | 5 | 4406 | Q3,Q4,Q5,Q6,Q7 | SOP-8_L4.9-W3.9-P1.27-LS6.0-BL |  | 4406 | HL(富海微) | C7431453 | LCSC
30 | 19 | 100k | R11,R21,R27,R33,R39,R45,R51,R87,R90,R93,R96,R100,R101,R104,R105,R106,R107,R110,R111 | R0402 | 100k
31 | 1 | 22k1 | R12 | R0402 | 22k1
32 | 20 | 10k | R13,R18,R20,R24,R26,R30,R32,R36,R38,R42,R44,R48,R50,R89,R95,R99,R103,R109,R116,R118 | R0402 | 10k
33 | 12 | 0R120 1W | R16,R17,R22,R23,R28,R29,R34,R35,R40,R41,R46,R47 | R1210 | 0R120 1W
34 | 13 | 1k | R19,R25,R31,R37,R43,R49,R71,R72,R73,R79,R88,R94,R117 | R0402 | 1k
35 | 8 | 10K | R52,R54,R56,R58,R60,R62,R64,R67 | R0402 | 10K
36 | 7 | 100 | R53,R55,R57,R59,R61,R63,R65 | R0402 | 100
37 | 1 | 10R | R66 | R0402 | 10R
38 | 6 | 1M | R68,R75,R76,R81,R83,R84 | R0402 | 1M
39 | 1 | 5.23kΩ | R86 | R0402 | 5.23kΩ | FRC0402F5231TS | FOJAN(富捷) | C2933105 | LCSC
40 | 2 | 360kΩ | R91,R97 | R0402 | 360kΩ | RC0402FR-07360KL | YAGEO(国巨) | C163471 | LCSC
41 | 1 | 13.7kΩ | R98 | R0402 | 13.7kΩ | 0402WGF1372TCE | UNI-ROYAL(厚声) | C25854 | LCSC
42 | 2 | 12k | R102,R108 | R0402 | 12k | 0402WGF1202TCE | UNI-ROYAL(厚声) |  | LCSC
43 | 4 | 5.1kΩ | R112,R113,R114,R115 | R0402 | 5.1kΩ | 0402WGF5101TCE | UNI-ROYAL(厚声) | C25905 | LCSC
44 | 1 | 0Ω | RN1 | RES-ARRAY-SMD_0603-8P-L3.2-W1.6-BL | 0Ω | YC164-JR-070RL | YAGEO(国巨) | C327053 | LCSC
45 | 1 | 10kΩ | RN2 | RES-ARRAY-SMD_0603-8P-L3.2-W1.6-BL | 10kΩ | 4D03WGJ0103T5E | UNI-ROYAL(厚声) | C29718 | LCSC
46 | 1 | TS-1187A-B-A-B | SW1 | SW-SMD_4P-L5.1-W5.1-P3.70-LS6.5-TL_H1.5 |  | TS-1187A-B-A-B | XKB Connectivity(中国星坤) | C318884 | LCSC
47 | 47 | Test-Point | TP1,TP3,TP4,TP5,TP7,TP8,TP9,TP10,TP11,TP12,TP13,TP14,TP15,TP16,TP17,TP18,TP19,TP20,TP21,TP22,TP23,TP24,TP25,TP26,TP27,TP28,TP29,TP30,TP31,TP32,TP33,TP34,TP35,TP36,TP37,TP38,TP39,TP40,TP41,TP42,TP43,TP44,TP45,TP46,TP47,TP48,TP49 | Test-Point-1mm
48 | 6 | TMC2226-SA-T | U2,U25,U26,U27,U28,U29 | HTSSOP-28_L9.8-W4.5-P0.65-LS6.6-BL-EP |  | TMC2226-SA-T | TRINAMIC | C705366 | LCSC
49 | 1 | SY8156IADC | U13 | TSOT-23-6_L2.9-W1.6-P0.95-LS2.8-BL |  | SY8156IADC |  | C9900034591 | LCSC
50 | 2 | USB2422T/MJ | U16,U61 | QFN-24_L4.0-W4.0-P0.50-BL-EP2.6 |  | USB2422T/MJ | MICROCHIP(美国微芯) | C622611 | LCSC
51 | 2 | GT-USB-9014A | U17,U62 | USB-C-SMD_GT-USB-9014A |  | GT-USB-9014A | G-Switch(品赞) | C3019721 | LCSC
52 | 5 | 1714955 | U18,U19,U20,U21,U24 | CONN-TH_P6.35_1714955 |  | 1714955 | Phoenix Contact(菲尼克斯) | C480584 | LCSC
53 | 6 | B4B-XH-A-BK(LF)(SN) | U30,U31,U32,U33,U34,U35 | CONN-TH_B4B-XH-A-BK-LF-SN |  | B4B-XH-A-BK(LF)(SN) | JST | C566013 | LCSC
54 | 3 | XY-XHB2.54-3A11 | U36,U40,U41 | HDR-TH_3P-P2.50-V-F-2 |  | XY-XHB2.54-3A11 | XYECONN(辛译) | C19271387 | LCSC
55 | 2 | GZP6897D2.5KPW | U37,U38 | SMD-8_L11.0-W7.0-P2.54-LS10.4-BL |  | GZP6897D2.5KPW | Sencoch(芯感智) | C3038057 | LCSC
56 | 1 | 4.7kΩ | U39 | RES-ARRAY-SMD_0603-8P-L3.2-W1.6-BL | 4.7kΩ | EXBV8V472JV | PANASONIC(松下) | C713475 | LCSC
57 | 4 | FIDUCIAL | U46,U47,U48,U49 | FIDUCIAL_1MM
58 | 2 | WAFER-PH2.0-2PZZ | U50,U51 | CONN-TH_2P-P2.00_HC-PH-2A-M |  | WAFER-PH2.0-2PZZ | XUNPU(讯普) | C5359599 | LCSC
59 | 1 | SN74LVC245APWR | U55 | TSSOP-20_L6.5-W4.4-P0.65-LS6.4-BL |  | SN74LVC245APWR | TI(德州仪器) | C7848 | LCSC
60 | 1 | STM32F407ZGT6_Blocks | U56 | LQFP-144_L20.0-W20.0-P0.50-LS22.0-BL
61 | 2 | SY8308RBC | U57,U59 | QFN-20_L3.5-W3.5-P0.50-BL-EP1.2 |  | SY8308RBC | Silergy(矽力杰) | C7427429 | LCSC
62 | 2 | 3.3uH | U58,U60 | IND-SMD_L9.2-W8.0 | 3.3uH | CYA0850-3.3UH | SHOU HAN(首韩) | C19268642 | LCSC
63 | 3 | 902-131A1011D10100 | USB4,USB5,USB6 | USB-A-TH__USB-AF-90 |  | 902-131A1011D10100 | 精拓金 | C2345 | LCSC
64 | 2 | 24MHz | X1,X3 | CRYSTAL-SMD_4P-L3.2-W2.5-BL | 24MHz | X322524MOB4SI | YXC(扬兴晶振) | C70590 | LCSC
65 | 1 | 8MHz | X2 | CRYSTAL-SMD_4P-L3.2-W2.5-BL-2 | 8MHz | TAXM8M4RFDCET2T | YJX(雅晶鑫) | C403948 | LCSC

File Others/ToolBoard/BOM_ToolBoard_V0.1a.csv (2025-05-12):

No. | Quantity | Comment | Designator | Footprint | Value | Manufacturer Part | Manufacturer | Supplier Part | Supplier
1 | 2 | M3 Mounting Hole | H1,H2 | PCB_MOUNT_M3_D
2 | 8 | B4B-XH-A-BK(LF)(SN) | U1,U2,U3,U4,U6,U7,U8,U9 | CONN-TH_B4B-XH-A-BK-LF-SN |  | B4B-XH-A-BK(LF)(SN) | JST | C566013 | LCSC
3 | 4 | B2B-PH-KL(LF)(SN) | U5,U10,U11,U12 | CONN-TH_2P-P2.00_2B-PH-KL |  | B2B-PH-KL(LF)(SN) | JST | C2683610 | LCSC

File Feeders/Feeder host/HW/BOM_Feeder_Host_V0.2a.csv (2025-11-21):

No. | Quantity | Comment | Designator | Footprint | Value | Manufacturer Part | Manufacturer | Supplier Part | Supplier
1 | 1 | 10uF | C4 | C0603 | 10uF | GRM188R61E106KA73D | muRata(村田) | C344022 | LCSC
2 | 8 | 100nF | C23,C24,C25,C28,C29,C30,C32,C35 | C0402 | 100nF | 0402X104K500CT | Walsin(华新科) | C387959 | LCSC
3 | 2 | 14pF | C26,C27 | C0805 | 14pF |  |  | C519919 | LCSC
4 | 2 | 4.7uF | C31,C33 | C0805 | 4.7uF | JMK212BJ475KG-T | TAIYO YUDEN(太诱) | C92788 | LCSC
5 | 1 | 1uF | C34 | C0805 | 1uF | CL21B105KOFNNNE | SAMSUNG(三星) | C24123 | LCSC
6 | 1 | 20021521-00010T1LF | CN5 | IDC-SMD_10P-P1.27_X1270WVS-2X05B-6TV01 |  | 20021521-00010T1LF | Amphenol | C2972785 | LCSC
7 | 2 | 1751264 | CN6,CN7 | CONN-TH_MKDS1-4-3.5 |  | 1751264 | Phoenix Contact(菲尼克斯) | C99845 | LCSC
8 | 1 | USBLC6-2P6 | D1 | SOT-666-6_L1.6-W1.2-P0.50-LS1.6-BR |  | USBLC6-2P6 | ST(意法半导体) | C15999 | LCSC
9 | 2 | 1N4148W | D2,D3 | SOD-123_L2.8-W1.8-LS3.7-RD |  | 1N4148W | MDD(辰达半导体) | C84367 | LCSC
10 | 1 | JK-mSMD075-33 | F1 | F1812 |  | JK-mSMD075-33 | JK(金科) | C369169 | LCSC
11 | 1 | APAN3105 | K1 | RELAY-TH_PANASONIC_APAN31XX |  | APAN3105 | PANASONIC(松下) | C90227 | LCSC
12 | 3 | ACT45B-510-2P-TL003 | L2,L3,L4 | IND-SMD_4P-L4.5-W3.2-TL |  | ACT45B-510-2P-TL003 | TDK | C76584 | LCSC
13 | 3 | NCD0805R1 | LED1,LED2,LED9 | LED0805-R-RD |  | NCD0805R1 | 国星光电 | C84256 | LCSC
14 | 6 | NCD0805G1 | LED3,LED4,LED6,LED7,LED8,LED10 | LED0805-R-RD |  | NCD0805G1 | 国星光电 | C84260 | LCSC
15 | 1 | SZYY0805Y | LED5 | LED0805-RD_YELLOW |  | SZYY0805Y | yongyu(永裕光电) | C434436 | LCSC
16 | 1 | MDD3400 | Q1 | SOT-23-3_L2.9-W1.5-P1.90-LS2.6-BR |  | MDD3400 | MDD(辰达半导体) | C427382 | LCSC
17 | 2 | 22Ω | R1,R2 | R0805 | 22Ω | RC0805JR-0722RL | YAGEO(国巨) | C108406 | LCSC
18 | 6 | 10kΩ | R8,R9,R10,R11,R29,R30 | R0402 | 10kΩ | RC0402FR-0710KL | YAGEO(国巨) | C60490 | LCSC
19 | 6 | 1kΩ | R12,R13,R14,R15,R35,R36 | R0402 | 1kΩ | RC0402FR-071KL | YAGEO(国巨) | C106235 | LCSC
20 | 3 | 120Ω | R18,R19,R31 | R0402 | 120Ω | ERJ2GEJ121X | PANASONIC(松下) | C412974 | LCSC
21 | 5 | 1kΩ | R20,R21,R23,R32,R33 | R0805 | 1kΩ | 0805W8F1001T5E | UNI-ROYAL(厚声) | C17513 | LCSC
22 | 3 | 10kΩ | R22,R24,R34 | R0805 | 10kΩ | 0805W8F1002T5E | UNI-ROYAL(厚声) | C17414 | LCSC
23 | 4 | 4.7kΩ | R25,R26,R27,R28 | R0805 | 4.7kΩ | 0805W8F4701T5E | UNI-ROYAL(厚声) | C17673 | LCSC
24 | 1 | TS-1187A-B-A-B | SW1 | SW-SMD_4P-L5.1-W5.1-P3.70-LS6.5-TL_H1.5 |  | TS-1187A-B-A-B | XKB Connectivity(中国星坤) | C318884 | LCSC
25 | 1 | TM-8764-1 | SW2 | SW-SMD_TM-8764-1 |  | TM-8764-1 | XKB Connectivity(中国星坤) | C381065 | LCSC
26 | 1 | PEC11S-929K-S0015 | SW4 | PEC11S-929K-S0015 |  | PEC11S-929K-S0015 | Bourns | 652-PEC11S929K-S0015 | Mouser
27 | 3 | MAX1487EDTR(XBLW) | U11,U13,U32 | SOP-8_L4.9-W3.9-P1.27-LS6.0-BL |  | MAX1487EDTR(XBLW) | XBLW(芯伯乐) | C41369526 | LCSC
28 | 3 | PESD2CAN-ES | U12,U14,U33 | SOT-23-3_L2.9-W1.3-P1.90-LS2.4-BR |  | PESD2CAN-ES | ElecSuper(静芯微) | C5180299 | LCSC
29 | 2 | TXS0104EDR(LX) | U27,U31 | SOIC-14_L8.7-W3.9-P1.27-LS6.0-BL |  | TXS0104EDR(LX) | LX(灵星芯微) | C22384787 | LCSC
30 | 1 | LM1117-3.3_C9900009419 | U28 | SOT-223-3_L6.5-W3.4-P2.30-LS7.0-BR |  | LM1117-3.3 | null | C9900009419 | LCSC
31 | 1 | 1714955 | U29 | CONN-TH_P6.35_1714955 |  | 1714955 | Phoenix Contact(菲尼克斯) | C480584 | LCSC
32 | 1 | STM32F072R8T6 | U30 | LQFP-64_L10.0-W10.0-P0.50-LS12.0-BL |  | STM32F072R8T6 | ST(意法半导体) | C87900 | LCSC
33 | 1 | 920-F62A2021S10104 | USB1 | MINI-USB-SMD_920-F62A2021S10104 |  | 920-F62A2021S10104 | 精拓金 | C2763184 | LCSC
34 | 1 | 25MHz | X1 | CRYSTAL-SMD_4P-L3.2-W2.5-BL | 25MHz | X322525MOB4SI | YXC(扬兴晶振) | C9006 | LCSC

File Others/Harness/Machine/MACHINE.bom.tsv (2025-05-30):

Id | Description | Qty | Unit | Designators
1 | Cable, 1 x 18 AWG | 0.1 | m | W_PE
2 | Cable, 2 x 15 AWG | 0.2 | m | W_PWRIN
3 | Cable, 3 x 18 AWG | 0.28 | m | W_MAINS
4 | Cable, 4 x 22 AWG | 15.19 | m | W_FEEDERS_PWR, W_HEAD_L, W_HEAD_R, W_LED, W_LEDBOT, W_PUMP, W_SOL_BLO, W_SOL_VAC, W_X, W_Y1, W_Y2, W_Z
5 | Cable, 4 x 24 AWG shielded | 3.5 | m | W_CAM_BOT, W_CAM_HEAD, W_FEEDERS
6 | Connector, 4 pins | 1 |  | USB_FEEDERS
7 | Connector, IEC, 3 pins | 1 |  | IEC
8 | Connector, JST, XH, female, 2 pins | 3 |  | END_CON, END_HEAD, LED_HEAD
9 | Connector, JST, XH, female, 4 pins | 14 |  | MOTOR_L_CON, MOTOR_L_HEAD, MOTOR_R_CON, MOTOR_R_HEAD, MOTOR_X_CON, MOTOR_X_PLUG, MOTOR_Y1_CON, MOTOR_Y1_PLUG, MOTOR_Y2_CON, MOTOR_Y2_PLUG, MOTOR_Z_CON, MOTOR_Z_HEAD, USB_BOT, USB_HEAD
10 | Connector, Pad, 2 pins | 1 |  | LED_BOT
11 | Connector, Ring crimp, GNYE | 1
12 | Connector, Screw terminal, 2 pins | 9 |  | CORE_24V, CORE_LED1OUT, CORE_LED2OUT, CORE_PUMP, CORE_SOL_BLO1, CORE_SOL_BLO2, CORE_SOL_VAC1, CORE_SOL_VAC2, PWRIN_FEEDERS
13 | Connector, Screw terminal, 4 pins | 1 |  | CORE_12VOUT
14 | Connector, Screw terminal, 5 pins | 1 |  | PSU
15 | Connector, USB, A, male, 4 pins | 3 |  | CORE_USB2, CORE_USB3, USB_CON
16 | Connector, solder, 2 pins | 5 |  | PUMP, SOL_BLO1, SOL_BLO2, SOL_VAC1, SOL_VAC2
17 | Crimp, SXH-001T-P0.6, 22-28 AWG | 62 |  | END_CON, END_HEAD, LED_HEAD, MOTOR_L_CON, MOTOR_L_HEAD, MOTOR_R_CON, MOTOR_R_HEAD, MOTOR_X_CON, MOTOR_X_PLUG, MOTOR_Y1_CON, MOTOR_Y1_PLUG, MOTOR_Y2_CON, MOTOR_Y2_PLUG, MOTOR_Z_CON, MOTOR_Z_HEAD, USB_BOT, USB_HEAD
18 | Faston, Female | 3 |  | IEC

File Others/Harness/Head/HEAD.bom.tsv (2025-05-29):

Id | Description | Qty | Unit | Designators
1 | Cable, 4 x 22 AWG | 0.6 | m | W_HEAD_L, W_HEAD_R, W_Z
2 | Cable, 4 x 24 AWG shielded | 0.23 | m | W_USB
3 | Connector, 2 pins | 1 |  | LED_PCB
4 | Connector, 4 pins | 4 |  | MOTOR_L, MOTOR_R, MOTOR_Z, USB_CAM
5 | Connector, JST XH, female, 2 pins | 1 |  | LED_CON
6 | Connector, JST XH, female, 4 pins | 4 |  | MOTOR_L_CON, MOTOR_R_CON, MOTOR_Z_CON, USB_CON
7 | Crimp, SXH-001T-P0.6, 22-28 AWG | 18 |  | LED_CON, MOTOR_L_CON, MOTOR_R_CON, MOTOR_Z_CON, USB_CON
8 | Heatshrink, Black or tone-on-tone | 0.22 | m | W_LED
9 | Wire, 24 AWG, BK | 0.22 | m | W_LED
10 | Wire, 24 AWG, RD | 0.22 | m | W_LED

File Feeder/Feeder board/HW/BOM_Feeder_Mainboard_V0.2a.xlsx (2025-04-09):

No. | Quantity | Comment | Designator | Footprint | Value | Manufacturer Part | Manufacturer | Supplier Part | Supplier
1 | 8 | 100nF | C1,C2,C3,C4,C5,C9,C13,C14 | C0805 | 100nF | CC0805KRX7R9BB104 | YAGEO(国巨) | C49678 | LCSC
2 | 1 | 10uF | C8 | C0805 | 10uF | JMK212BJ106KD-T | TAIYO YUDEN(太诱) | C92786 | LCSC
3 | 1 | 2.2uF | C10 | C0805 | 2.2uF | CL21B225KOFNNNE | SAMSUNG(三星) | C28234 | LCSC
4 | 1 | 220uF | C11 | CAP-SMD_L7.3-W4.3-FD | 220uF | EEFCX0J221YR | PANASONIC(松下) | C141444 | LCSC
5 | 1 | 100uF | C12 | C1210 | 100uF | MSASE32MAB5107MPNA01 | TAIYO YUDEN(太诱) | C5372270 | LCSC
6 | 3 | 1N4148W | D1,D2,D3 | SOD-123_L2.8-W1.8-LS3.7-RD |  | 1N4148W | MDD(辰达半导体) | C84367 | LCSC
7 | 1 | JK-mSMD075-33 | F1 | F1812 |  | JK-mSMD075-33 | JK(金科) | C369169 | LCSC
8 | 1 | ACT45B-510-2P-TL003 | L1 | IND-SMD_4P-L4.5-W3.2-TL |  | ACT45B-510-2P-TL003 | TDK | C76584 | LCSC
9 | 1 | 33uH | L2 | IND-SMD_L7.1-W6.6_SRP6030VA | 33uH | SL0630-330M | 台湾陆海 | C22463826 | LCSC
10 | 2 | SK6812SIDE-A-RVS | LED1,LED2 | LED-SMD_4P-L4.0-W1.6-L |  | SK6812SIDE-A-RVS | 欧思科光电 | C2890037 | LCSC
11 | 1 | SZYY0805Y | LED4 | LED0805-RD_YELLOW |  | SZYY0805Y | yongyu(永裕光电) | C434436 | LCSC
12 | 2 | NCD0805G1 | LED5,LED6 | LED0805-R-RD |  | NCD0805G1 | 国星光电 | C84260 | LCSC
13 | 1 | NCD0805R1 | LED7 | LED0805-R-RD |  | NCD0805R1 | 国星光电 | C84256 | LCSC
14 | 3 | 10kΩ | R2,R15,R16 | R0805 | 10kΩ | 0805W8F1002T5E | UNI-ROYAL(厚声) | C17414 | LCSC
15 | 2 | 470Ω | R3,R4 | R0805 | 470Ω | 0805W8F4700T5E | UNI-ROYAL(厚声) | C17710 | LCSC
16 | 2 | 220Ω | R5,R14 | R0805 | 220Ω | 0805W8F2200T5E | UNI-ROYAL(厚声) | C17557 | LCSC
17 | 4 | 1kΩ | R6,R7,R8,R9 | R0805 | 1kΩ | 0805W8F1001T5E | UNI-ROYAL(厚声) | C17513 | LCSC
18 | 1 | 100kΩ | R10 | R0805_NEW | 100kΩ | RC0805FR-07100KL | YAGEO(国巨) | C96346 | LCSC
19 | 1 | 33kΩ | R11 | R0805 | 33kΩ | 0805W8F3302T5E | UNI-ROYAL(厚声) | C17633 | LCSC
20 | 3 | TS24CA 250gf 013 | SW1,SW2,SW3 | SW-SMD_L4.7-W3.5-P3.35-EH |  | TS24CA 250gf 013 | SHOU HAN(首韩) | C5373430 | LCSC
21 | 1 | YZ165615055F-04025-01 | U1 | CONN-SMD_4P-L11.0-W5.5-P2.50_YZ165615055F-04025-01 |  | YZ165615055F-04025-01 | Xinyangze(鑫扬泽) | C5296819 | LCSC
22 | 1 | ATMEGA328PB-AU | U2 | TQFP-32_L7.0-W7.0-P0.80-LS9.0-BL |  | ATMEGA328PB-AU | MICROCHIP(美国微芯) | C132230 | LCSC
23 | 1 | ICSP_HEADER_CUST | U4 | HDR-M-2.54_1X6
24 | 1 | MAX1487EDTR(XBLW) | U6 | SOP-8_L4.9-W3.9-P1.27-LS6.0-BL |  | MAX1487EDTR(XBLW) | XBLW(芯伯乐) | C41369526 | LCSC
25 | 1 | PESD2CAN-ES | U7 | SOT-23-3_L2.9-W1.3-P1.90-LS2.4-BR |  | PESD2CAN-ES | ElecSuper(静芯微) | C5180299 | LCSC
26 | 1 | TMI2284Q | U8 | SOP-8_L4.9-W3.9-P1.27-LS6.0-TR
27 | 1 | DRV8833PWPR | U9 | TSSOP-16_L5.0-W4.4-P0.65-LS6.4-BL-EP |  | DRV8833PWPR | TI(德州仪器) | C50506 | LCSC

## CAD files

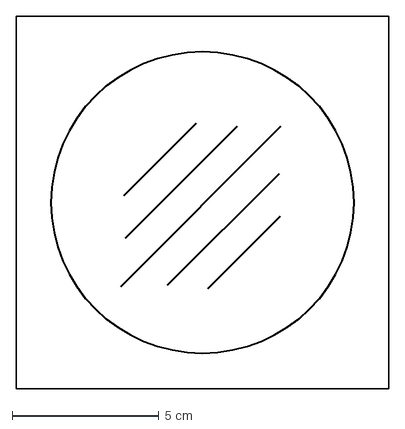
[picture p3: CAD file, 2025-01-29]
assets/Orion_logo.dxf
12.7 x 12.7 cm

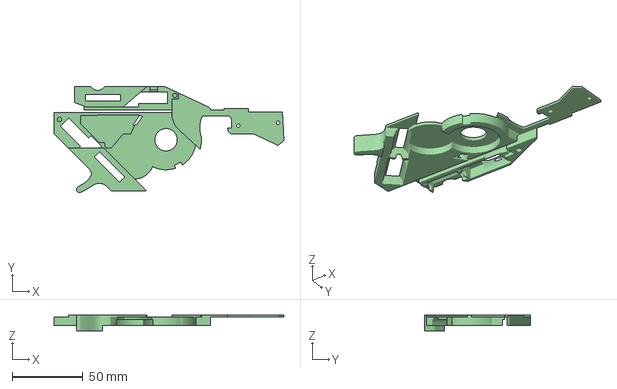
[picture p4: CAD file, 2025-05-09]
CAD/Feeders/V2a/3MF/UpperBody.3mf
162.2 x 74.9 x 11.0 mm

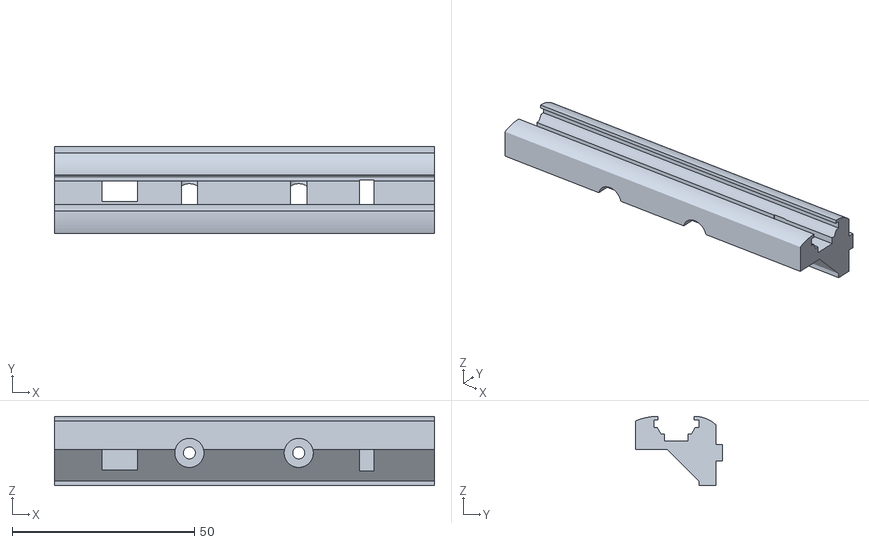
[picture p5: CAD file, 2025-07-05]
CAD/OrionPnP/Feeder rail/Rail_Strip_Holder_a.stl
104.2 x 23.8 x 19.0

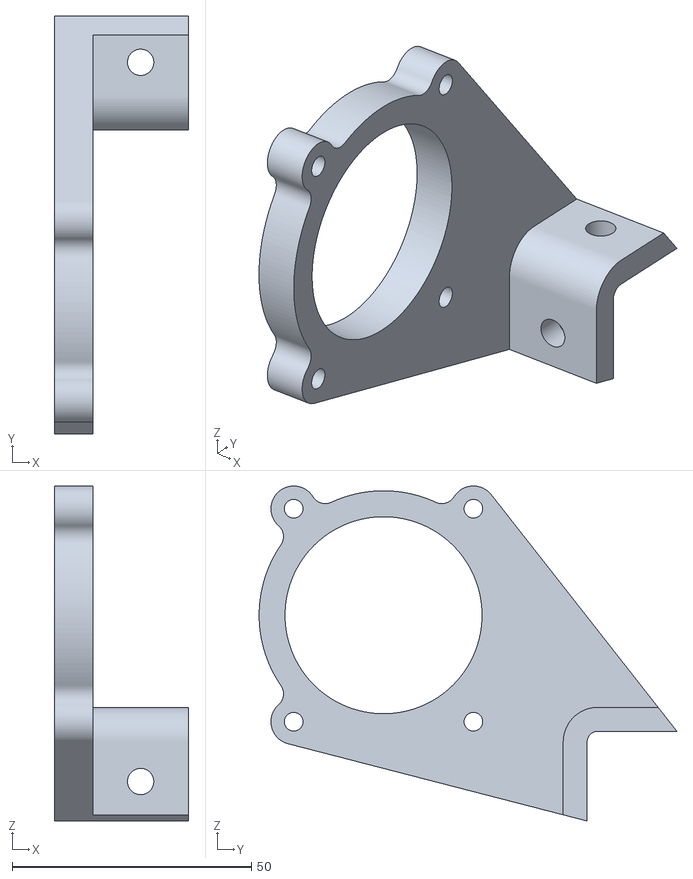
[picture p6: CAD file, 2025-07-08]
CAD/OrionPnP/Frame/Frame_Pump_bracket_b.stl
28.0 x 87.3 x 70.0

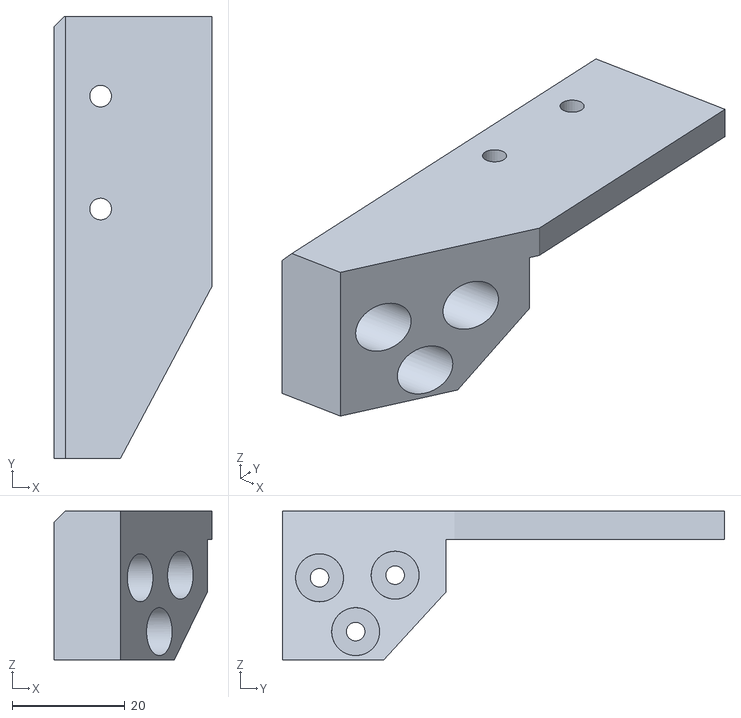
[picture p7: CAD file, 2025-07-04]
CAD/OrionPnP/Head/Head_Chain_mount.stl
28.0 x 78.4 x 26.3

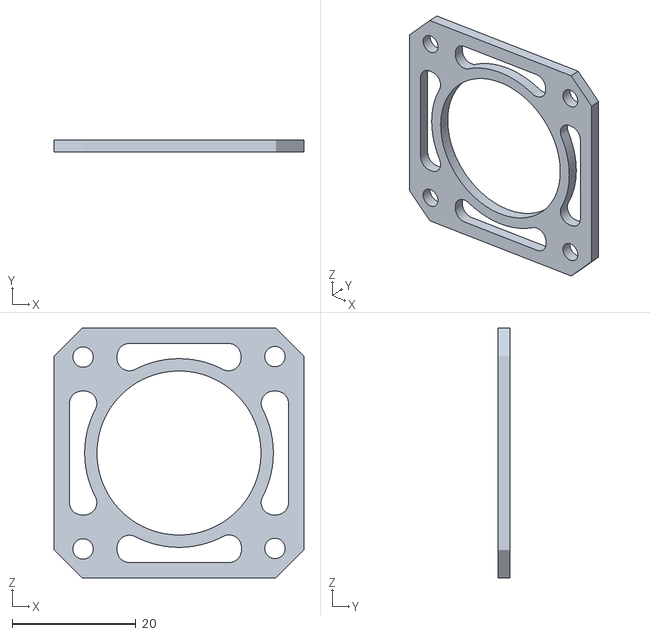
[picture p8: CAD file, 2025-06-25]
CAD/OrionPnP/X axis/X_Motor_Spacer.stl
40.4 x 2.00 x 40.4

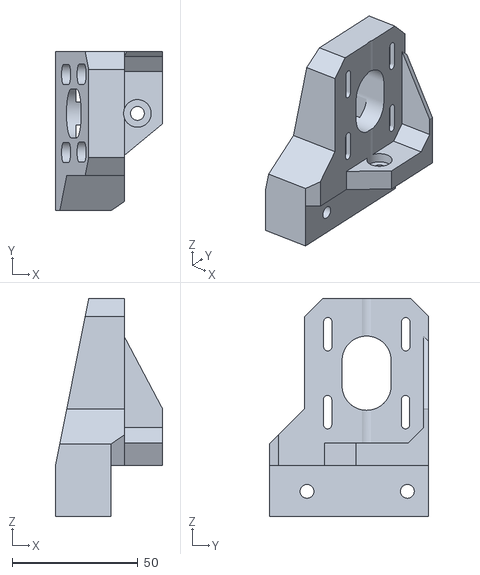
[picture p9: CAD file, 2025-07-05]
CAD/OrionPnP/Y axis/Y_motor_mount_R.stl
42.6 x 63.4 x 86.7

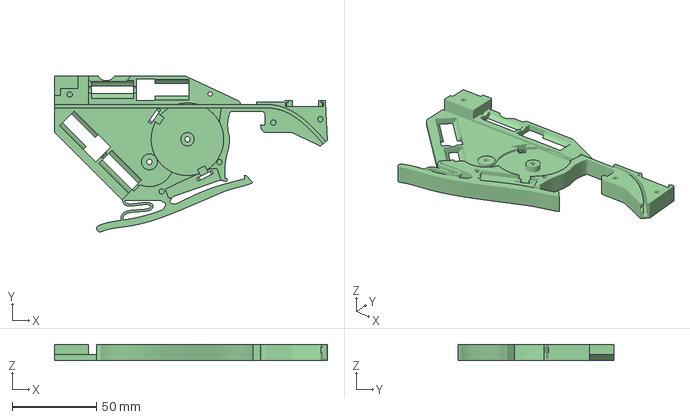
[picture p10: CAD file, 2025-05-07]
CAD/Feeders/V2a/3MF/LowerBody.3mf
162.2 x 92.6 x 9.70 mm

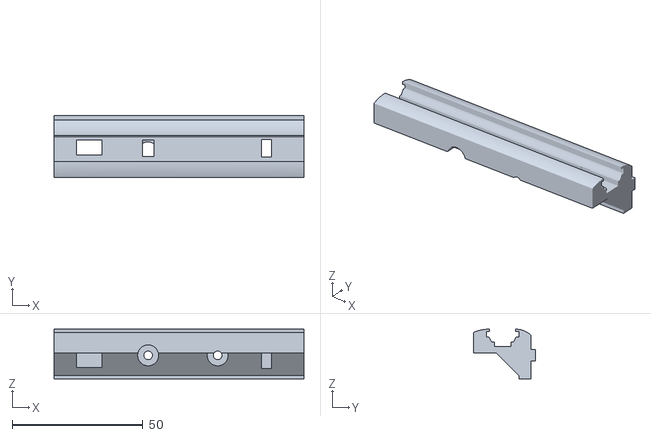
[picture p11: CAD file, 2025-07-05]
CAD/OrionPnP/Feeder rail/Rail_Strip_Holder_b.stl
95.6 x 23.8 x 19.0

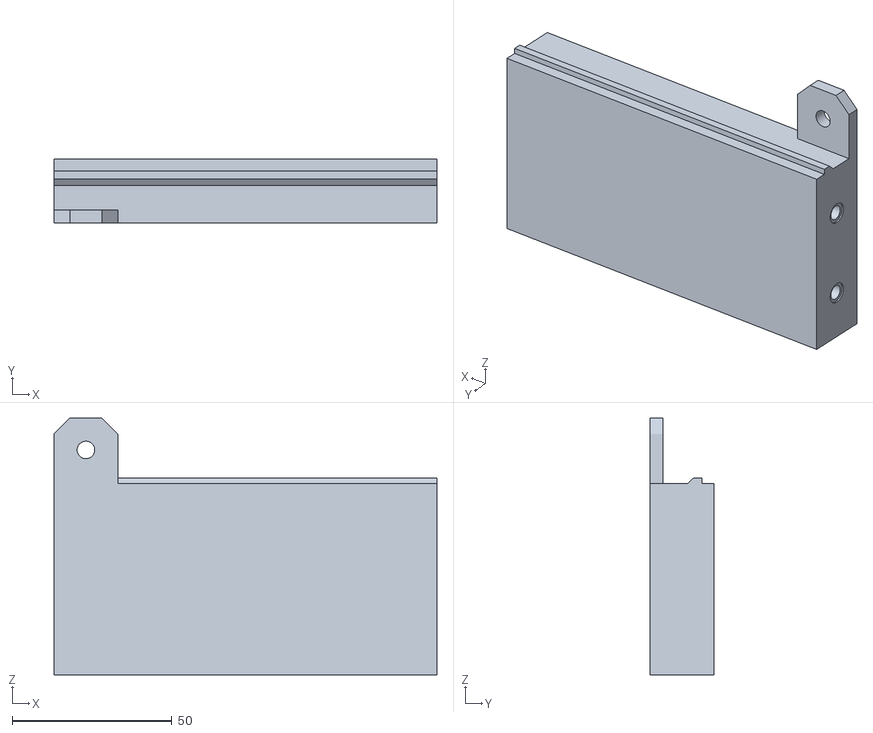
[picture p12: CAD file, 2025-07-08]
CAD/OrionPnP/Frame/Frame_vacuum_tank.stl
120.0 x 20.0 x 80.5

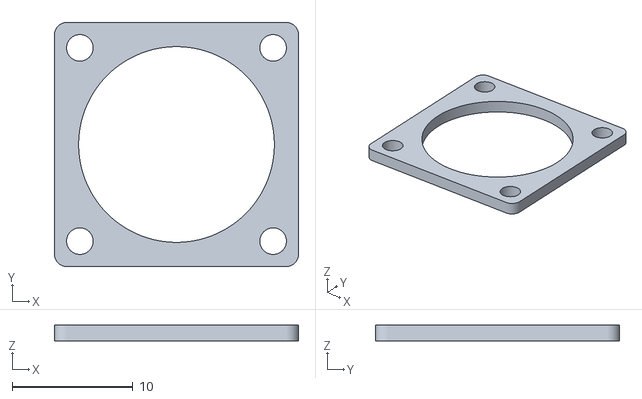
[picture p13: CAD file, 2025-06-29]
CAD/OrionPnP/Head/Head_Spacer_Nozzle.stl
20.2 x 20.2 x 1.30

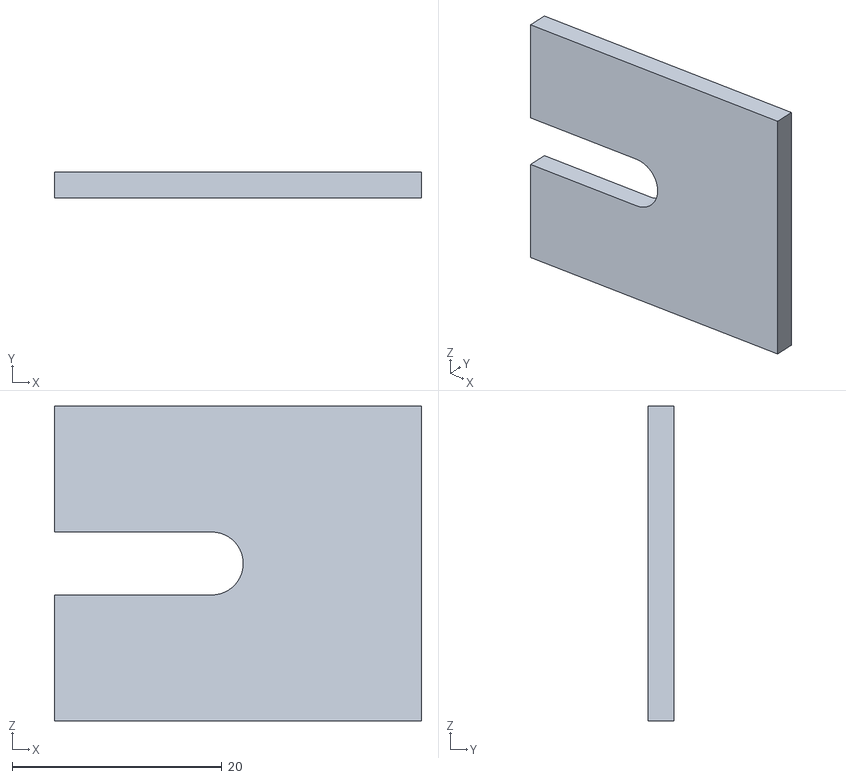
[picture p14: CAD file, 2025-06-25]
CAD/OrionPnP/X axis/X_Pulley_Spacer.stl
35.0 x 2.50 x 30.0

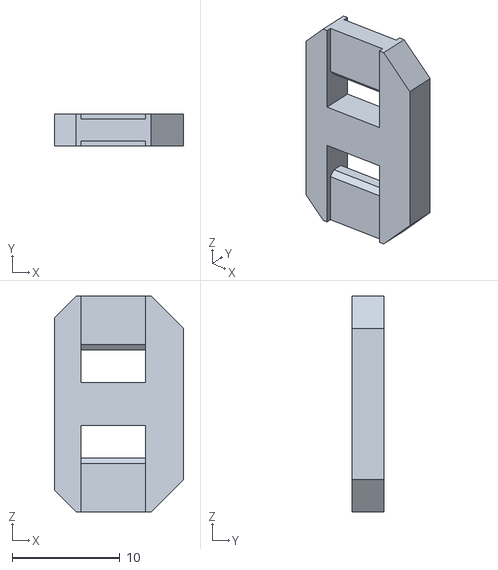
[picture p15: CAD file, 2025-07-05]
CAD/OrionPnP/Y axis/Y_Belt_mount.stl
12.0 x 3.00 x 20.0

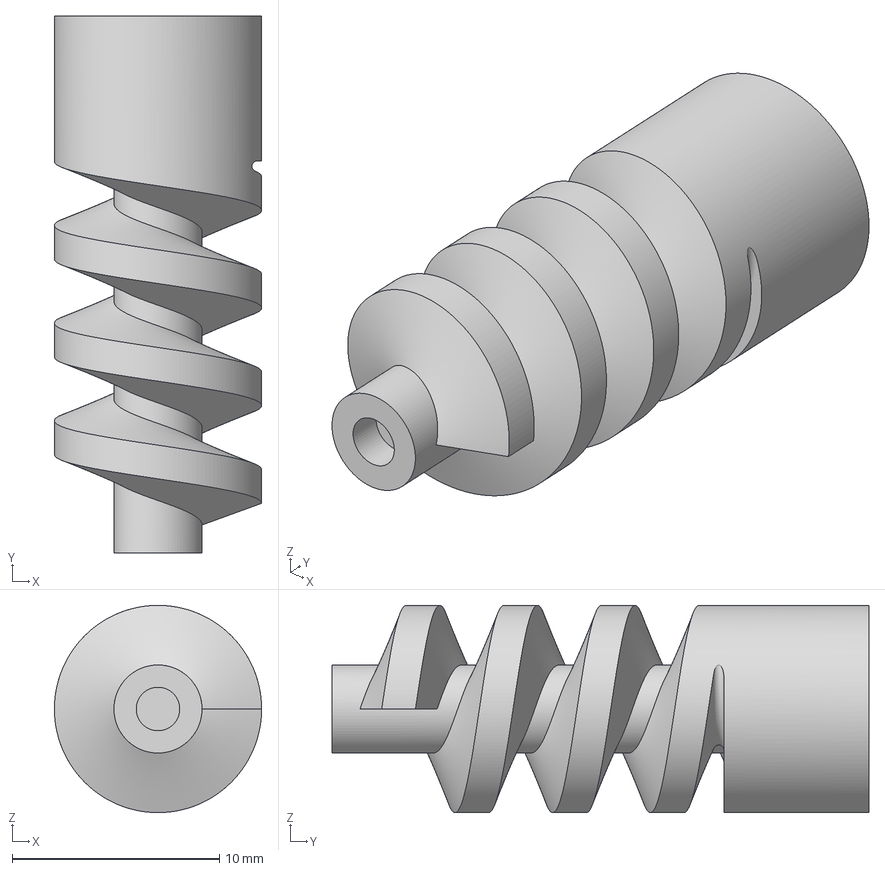
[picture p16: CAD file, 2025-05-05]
CAD/Feeders/V2a/3MF/Helical_Drive.3mf
10.00 x 25.9 x 10.00 mm

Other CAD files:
CAD/OrionPnP/Frame/Frame_Pump_bracket_a.stl
CAD/OrionPnP/Head/Head_Base_plate.stl
CAD/OrionPnP/X axis/X_motor_carriage.stl
CAD/OrionPnP/Y axis/Y_motor_mount_L.stl
CAD/Feeders/V2a/3MF/DragGear.3mf
CAD/Feeders/V2a/3MF/DragTensioner.3mf
CAD/Feeders/V2a/3MF/Drivegear.3mf
CAD/Feeders/V2a/3MF/MidGear.3mf
CAD/Feeders/V2a/3MF/NumberCarrier.3mf
CAD/Feeders/V2a/STL/DragGear.stl
CAD/Feeders/V2a/STL/DragTensioner.stl
CAD/Feeders/V2a/STL/Drivegear.stl
CAD/Feeders/V2a/STL/Helical_Drive.stl
CAD/Feeders/V2a/STL/LowerBody.stl
CAD/Feeders/V2a/STL/MidGear.stl
CAD/Feeders/V2a/STL/NumberCarrier.stl
CAD/Feeders/V2a/STL/UpperBody.stl
CAD/OrionPnP/Frame/BASE_HALF.dxf
CAD/OrionPnP/Frame/Frame_Camera_mount.stl
CAD/OrionPnP/Frame/Frame_Chain adapter.stl
CAD/OrionPnP/Frame/Frame_Chain_mount.stl
CAD/OrionPnP/Frame/Frame_Core_mount_a.stl
CAD/OrionPnP/Frame/Frame_Core_mount_b.stl
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

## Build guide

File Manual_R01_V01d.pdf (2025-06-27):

# OrionPnP

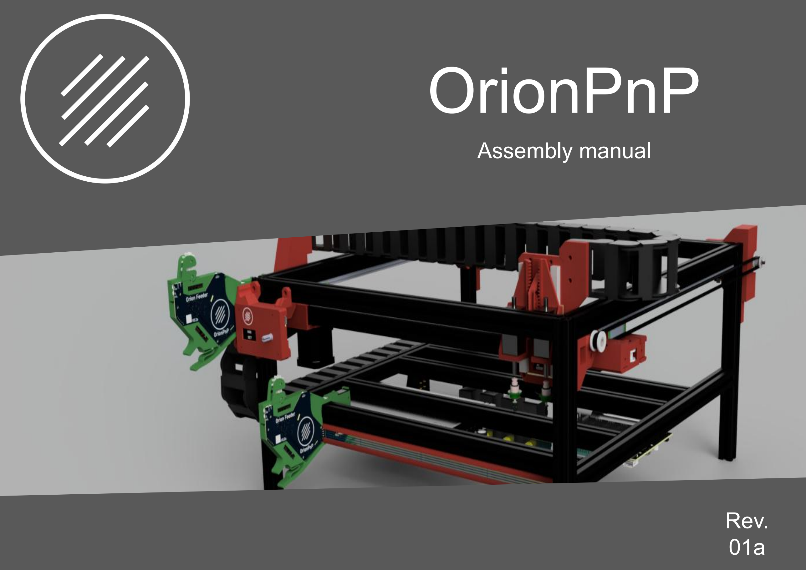
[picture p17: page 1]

Assembly manual

Rev.
01a 1

## Before we start…

### A word about safety

You are about to build a machine, powered by mains voltage, which could become DEADLY if not handled properly. Please consult a professional if you are unsure on how to proceed when the symbol is shown.
We are going to build a machine, capable of injuring you and/or others. There is no pride in getting hurt or worse, so be careful and always wear adequate protective gear when needed.
In the manual the symbol is used whenever special care is required. Make sure to read the manual before starting!

## A word about this project

### OrionPnP

The OrionPnP project has been conceived to bring good performance pick-and-place machines to makers, with solid and reliable operation, the project aims to handle 0402 components to empower makers and allow smaller boards to be manufactured. The heart of the project is the open source software OpenPNP (https://openpnp.org/) of course!
The project is open source, and as such every reference in this manual is made to a specific machine version. Mods, add-ons and other non official modifications will have their own guides, so follow those.
The source of each and every information is (and will always be) the Github repository. (https://github.com/TheIgorMC/orionPnP)
Go and check the project if you haven’t already, read the wiki and if this is the project for you, get ready to build!

## How to navigate this manual

### The manual

This manual will take you step by step from a bunch of components to a working OrionPnP machine. Each step is written as clearly as possible, but the drawings and the representations should clarify any doubt.
Minor differences might be noticeable but if the difference doesn’t affect the
assembly, the step is still valid. (e.g. toothed profile on belt holders might be different)
Several tools will be needed, and the list can be found in the BOM. 3D printed parts require no particular setting and can be printed in PLA, only motor mounts should be printed in heat resistant material as ABS, ASA or PETG. If using PLA for all, print the motor spacers in ABS or ASA to prevent issues!
Several screws will be used, make sure to reference the BOM for the codes relative to those. A 1:1 scale page of most screws and fasteners is in the works. For this to be useful you must print it without scaling from the printer!

## Main frame

### Get the profiles ready

The machine is built around 2020 aluminium profiles, their sizes and amounts are:

All these profiles need to be prepared for the next step.
No drilling or tapping is required by design, but you can tap the ends and use screws to reinforce the connections if you really want to.
We will start the build by assembling the “bed”, where the work surface will go later on and the rest of the frame.
4x 250mm for the legs | 6x 435mm for the X axis and bracing
1x 478mm for the X axis itself | 4x 550mm for the Y axis

## Main frame

### Prepare corner brackets

Prepare the corner brackets as illustrated, using M4x8mm button head screws and a square nut. A washer is recommended.
In total we need 20 brackets prepared this way. Note: depending on your corner brackets you might also use M5x8mm screws.
Then prepare the 6x 435mm profiles as illustrated below. Do the same for 2x 550mm profiles. Only tighten screws on the profile side of the bracket. Leave the other nut loose!

As level as possible

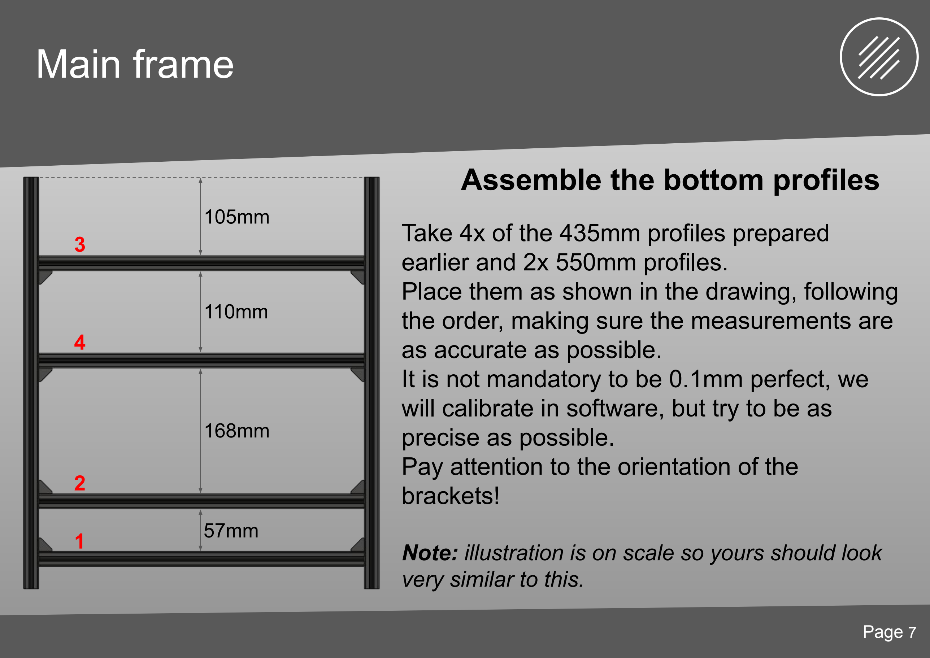
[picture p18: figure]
Main frame; Assemble the bottom profiles; Take 4x of the 435mm profiles prepared earlier and 2x 550mm profiles.; as accurate as possible.; precise as possible. Pay attention to the orientation of the brackets!; very similar to this.

Place them as shown in the drawing, following the order, making sure the measurements are

It is not mandatory to be 0.1mm perfect, we will calibrate in software, but try to be as

Note: illustration is on scale so yours should look

## Main frame

Tap the legs of the frame

Take the 4 250mm profiles and tap one end with an M5 thread. This will be used
to fix the feet on them later on. Only about 6mm need to be threaded.

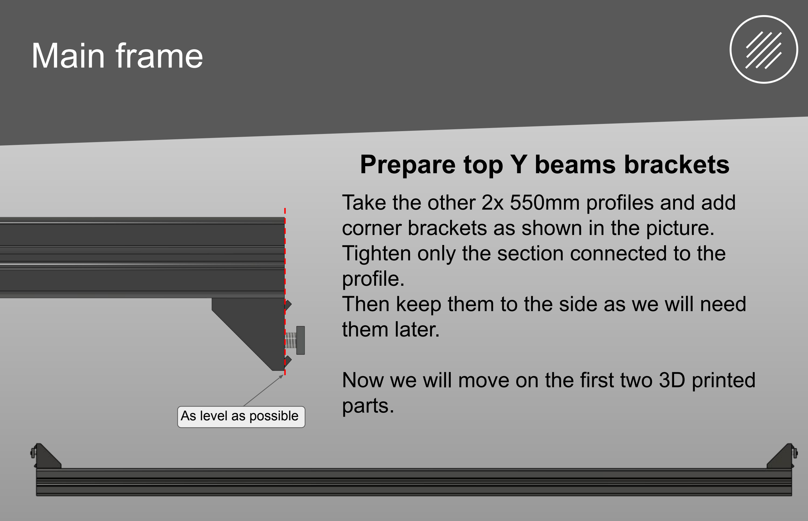
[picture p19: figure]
Main frame; profile.; them later.; parts.; Prepare top Y beams brackets; As level as possible

Take the other 2x 550mm profiles and add corner brackets as shown in the picture. Tighten only the section connected to the

Then keep them to the side as we will need

Now we will move on the first two 3D printed

## Main frame

Page

We will need the Y_Corner_idler_holder_R and Y_Corner_idler_holder_L files printed.
We will also need:
2x M3 heat set inserts
2x M5 heat set inserts
4x M5 square nuts
4x M5x10mm button head screws 2x M5x35mm cap head screws
2x Toothed GT2 idlers for 6mm belts

Steps will need to be done on both R and L pieces, they are symmetrical.

### Prepare the idler holders

## Main frame

Turn the piece 180°

M3

M5

Note: L idler holder shown in the pictures

Y_Corner_idler_holder

## Main frame

Add square nuts

Note: L idler holder shown in the pictures

## Main frame

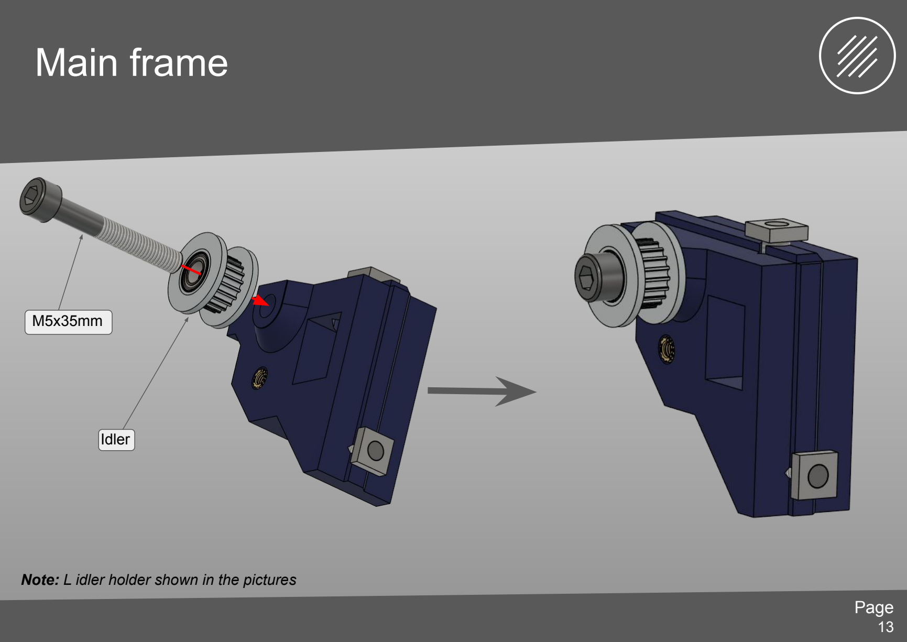
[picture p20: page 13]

Note: L idler holder shown in the pictures

M5x35mm

Idler

## Main frame

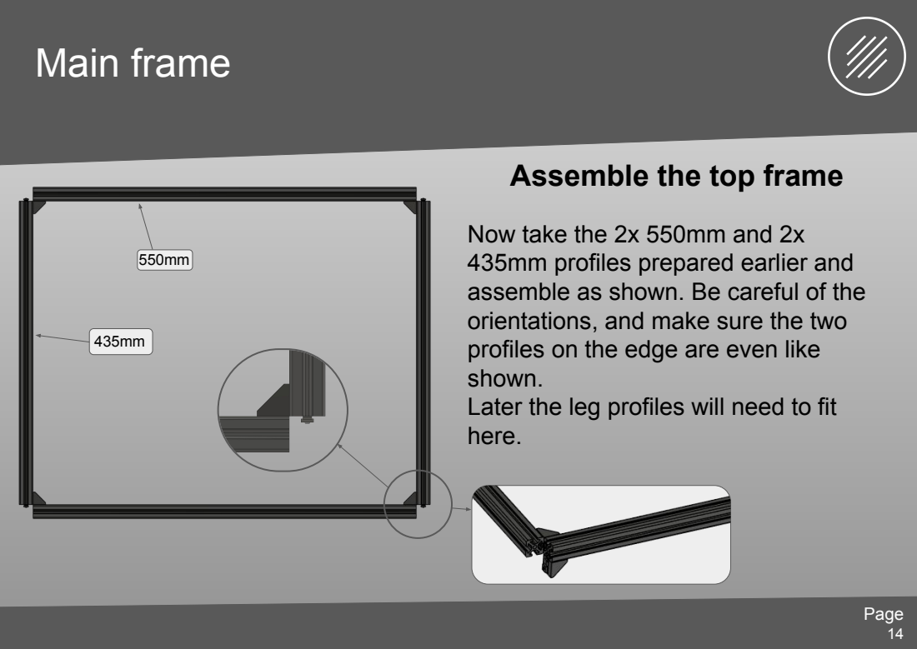
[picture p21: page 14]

Assemble the top frame

Now take the 2x 550mm and 2x
435mm profiles prepared earlier and
assemble as shown. Be careful of the
orientations, and make sure the two
profiles on the edge are even like
shown.
Later the leg profiles will need to fit
here.

## Main frame

Mount the idler holders

If this bracket is in the
way, undo it and slide the
holder in, then realign it.

Note: L idler holder shown in the pictures

## Main frame

### Finished top frame

The top frame is now
finished, make sure it
looks like the picture
shown.
Do not worry at this point if it is not aligned, we will take care in the next steps about it.

## Main frame

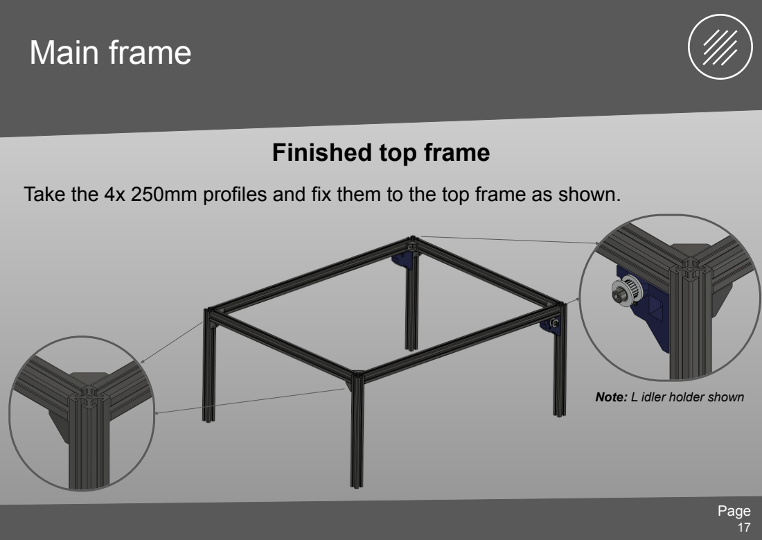
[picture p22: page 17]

Finished top frame

Take the 4x 250mm profiles and fix them to the top frame as shown.

Note: L idler holder shown

## Main frame

### Finish the frame

Now slide in the bottom frame as shown and screw the corner brackets to fix it, take care about the measurements referred
below.

120mm

BACK | FRONT

Note: Keep in mind the front placement!

## Main frame

### Square the frame

This is the time to square the frame. To do this lay the machine on the top frame, having care to check if there is any wobble.
Undo screws and fix all the profiles in their correct positions, making sure to measure the distances when needed.
If the frame is square, you should have all diagonals being equal (or close enough).
Once you are done, we can move on to the next section: rails!

## Main frame

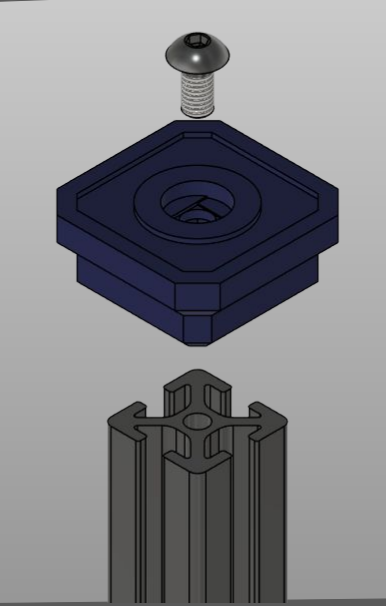
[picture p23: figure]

### Attach feet

Depending on the revision of the CAD, you might have different feet designs, but they all fix to the machine in the same way. In the pictures we will show the standard feet. They would require a rubberized insert to add grip.
There is a “tilt” foot for the back of the machine available, this allows to easily tilt the OrionPnP for working easier on its electronics etc…

## Y Axis rails

### Prepare the rails and fasteners

For this section, we will need 2x 500mm MGN12 linear rails to make the two Y axis rails. We need to clean them with some isopropyl alcohol to degrease them first! Remove the shuttles if you have the right holder for the carriage, otherwise leave it on!

Take care while removing the carriages to not losing the balls inside! There are plenty of tutorials on how to properly clean rails!

When clean, regrease it properly and get ready these fasteners:
- 20x M3x8mm Socket head screws
- 20x M3 hammer T-nut

## Y Axis rails

### Check the rails

Before moving on, slide the rails back and forth as shown. Check if you can smoothly move them, if not try cleaning them better and applying grease if you did not earlier.

### NEVER LET THE CARRIAGE SLIDE OFF!

## Y Axis rails

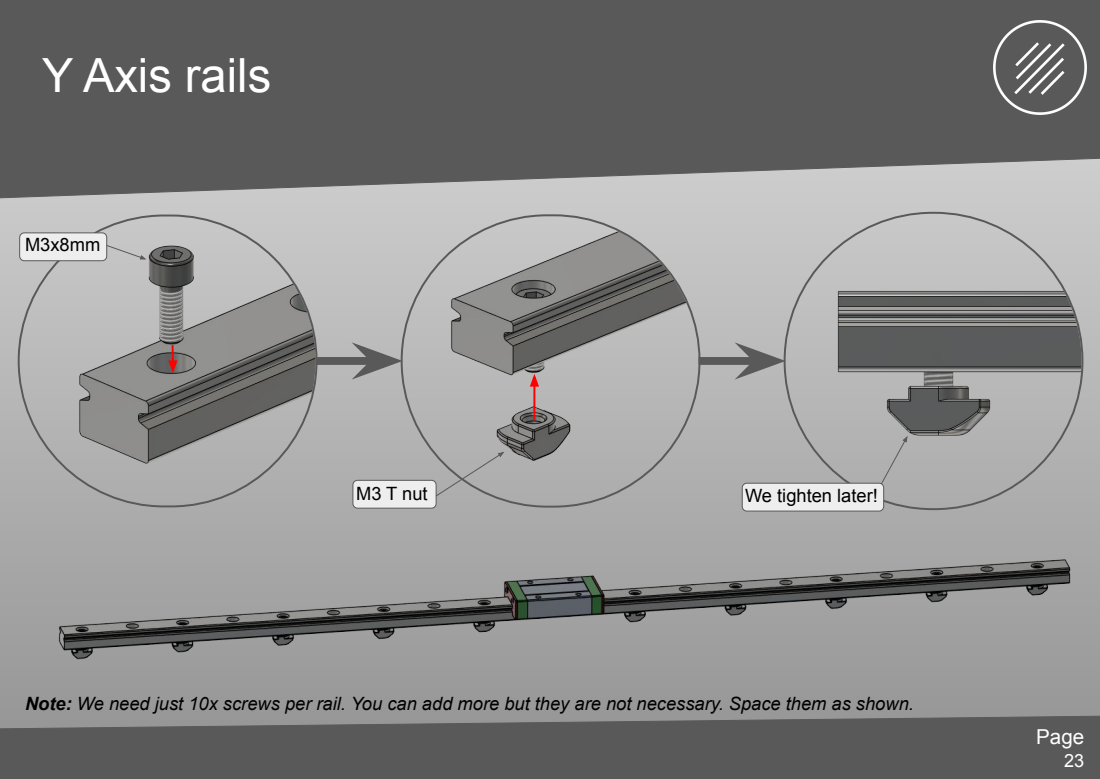
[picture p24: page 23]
M3 T nut; We tighten later!

Note: We need just 10x screws per rail. You can add more but they are not necessary. Space them as shown.

## Y Axis rails

Now mount the rails, making sure to tighten gradually the
screws, starting from one side to keep it even.
Pay attention, the rail should bump into the idler holders!

Repeat for both rails before moving on!

## Y Axis rails

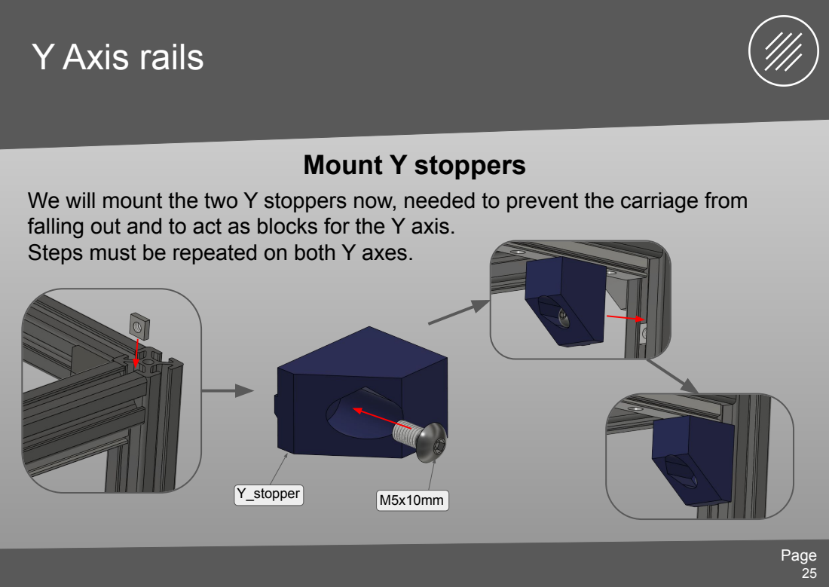
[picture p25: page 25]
Mount Y stoppers; M5x10mm Y_stopper

We will mount the two Y stoppers now, needed to prevent the carriage from
falling out and to act as blocks for the Y axis.
Steps must be repeated on both Y axes.

## X axis

For the X axis we will need the 400mm MGN12 rail, once again we need to clean it from the oil and grease it as before:

Take care while removing the carriages to not losing the balls inside! There are plenty of tutorials on how to properly clean rails!

When clean, regrease it properly and get ready to assemble. We will need plenty of fasteners and printed parts, we will also need heat set inserts so be ready to get those in place too.
The printed parts list is in the X axis section, and the files start all with “X_” so you will need all of those.

### Prepare the rails and printed parts

## X axis

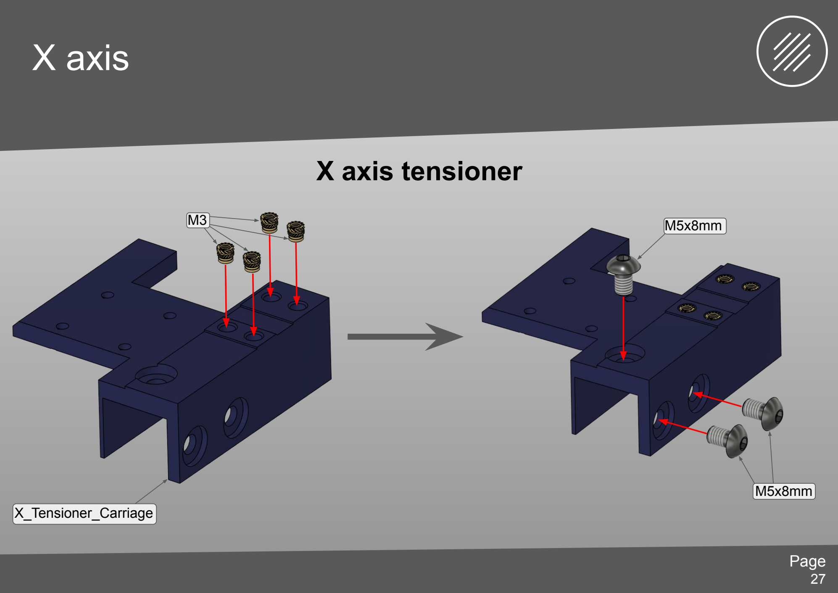
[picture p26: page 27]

### X axis tensioner

X_Tensioner_Carriage

M3

M5x8mm

M5x8mm

## X axis

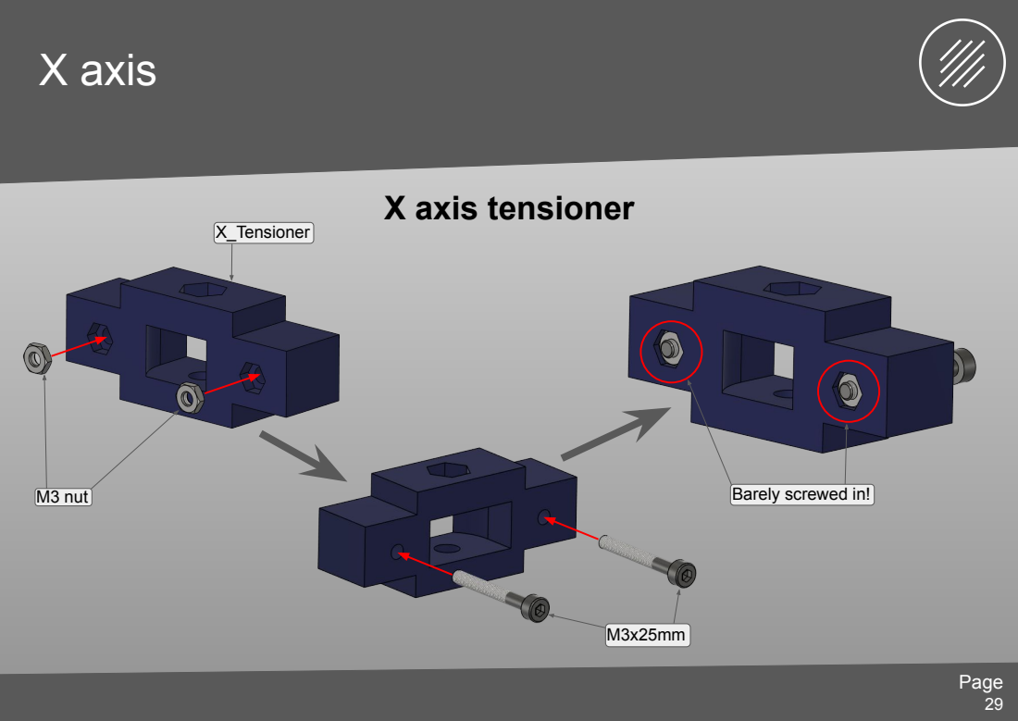
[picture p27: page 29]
X axis tensioner; M3 nut; X_Tensioner

Barely screwed in!

## X axis

Note: Make sure the idler spins freely, if not loosen the screw a bit until it does.

## X axis

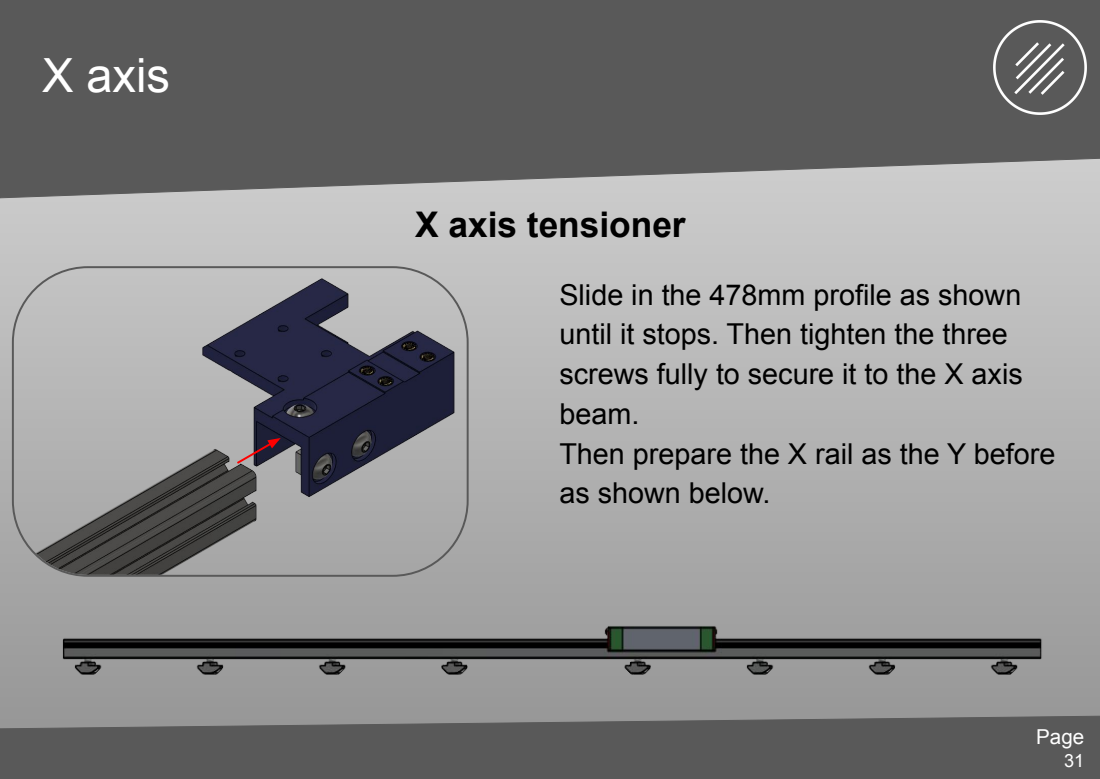
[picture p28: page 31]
X axis tensioner

Slide in the 478mm profile as shown
until it stops. Then tighten the three
screws fully to secure it to the X axis
beam.
Then prepare the X rail as the Y before
as shown below.

## X axis

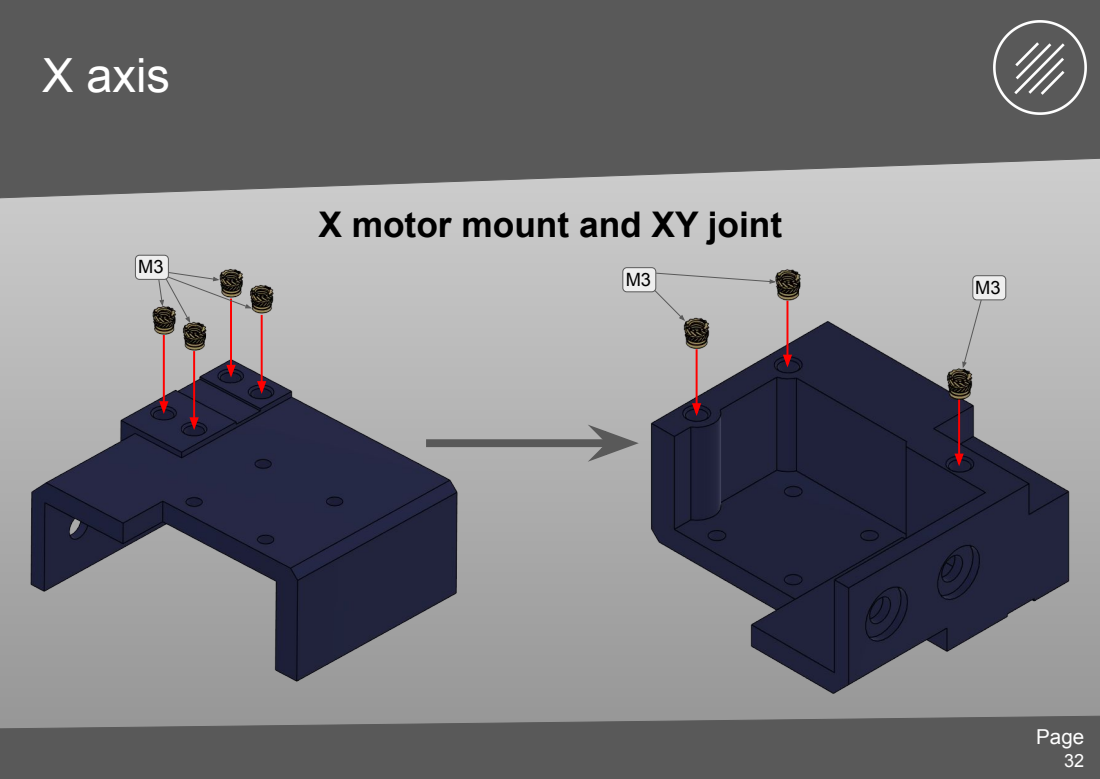
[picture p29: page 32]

X motor mount and XY joint

## X axis

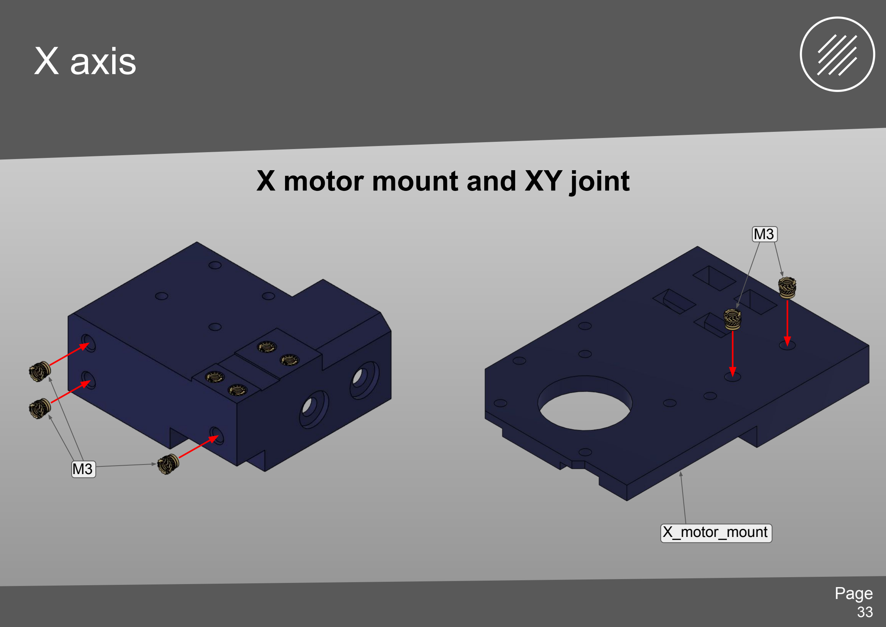
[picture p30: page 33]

### X motor mount and XY joint

M3

X_motor_mount

M3

## X axis

X motor mount and XY joint

If you printed the pieces in non heat
resistant materials, we strongly
recommend to use M3x10mm screws and
print the X_Motor_Spacer file in heat
resistant materials like ASA, ABS or
PETG (not as resistant, but should be
fine).

Motor connector should

face this way

Make sure the motor connector faces
the correct way!

## X axis

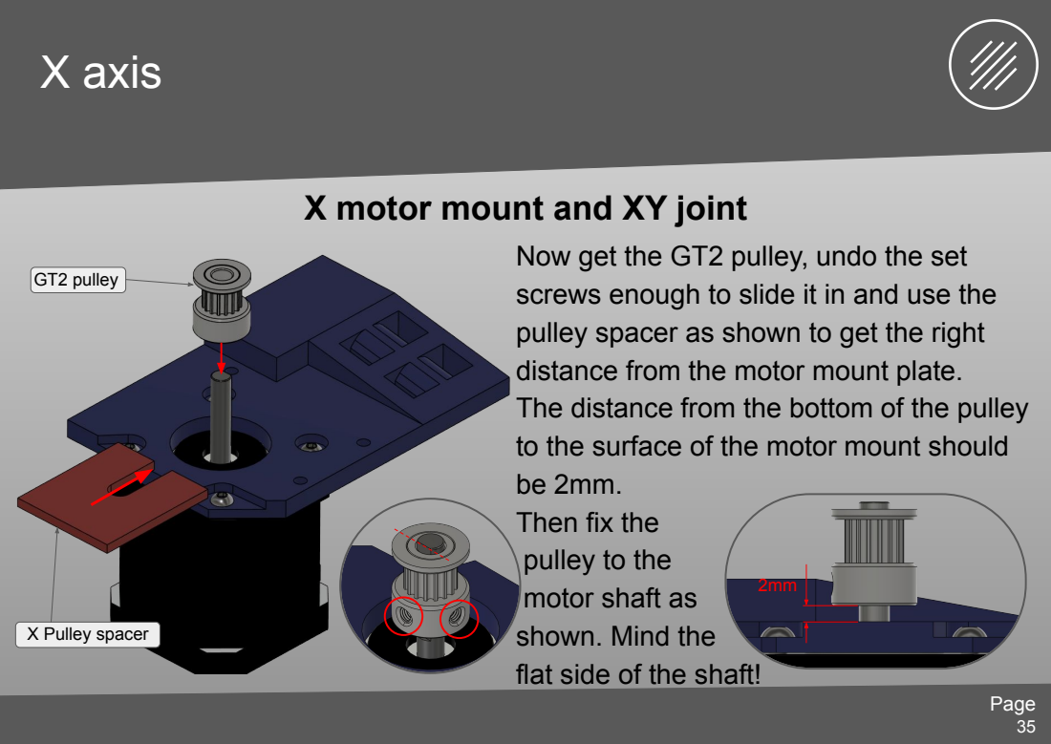
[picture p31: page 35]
GT2 pulley; X Pulley spacer

X motor mount and XY joint

Now get the GT2 pulley, undo the set
screws enough to slide it in and use the
pulley spacer as shown to get the right
distance from the motor mount plate.
The distance from the bottom of the pulley
to the surface of the motor mount should
Then fix the
pulley to the
motor shaft as
shown. Mind the
flat side of the shaft!

## X axis

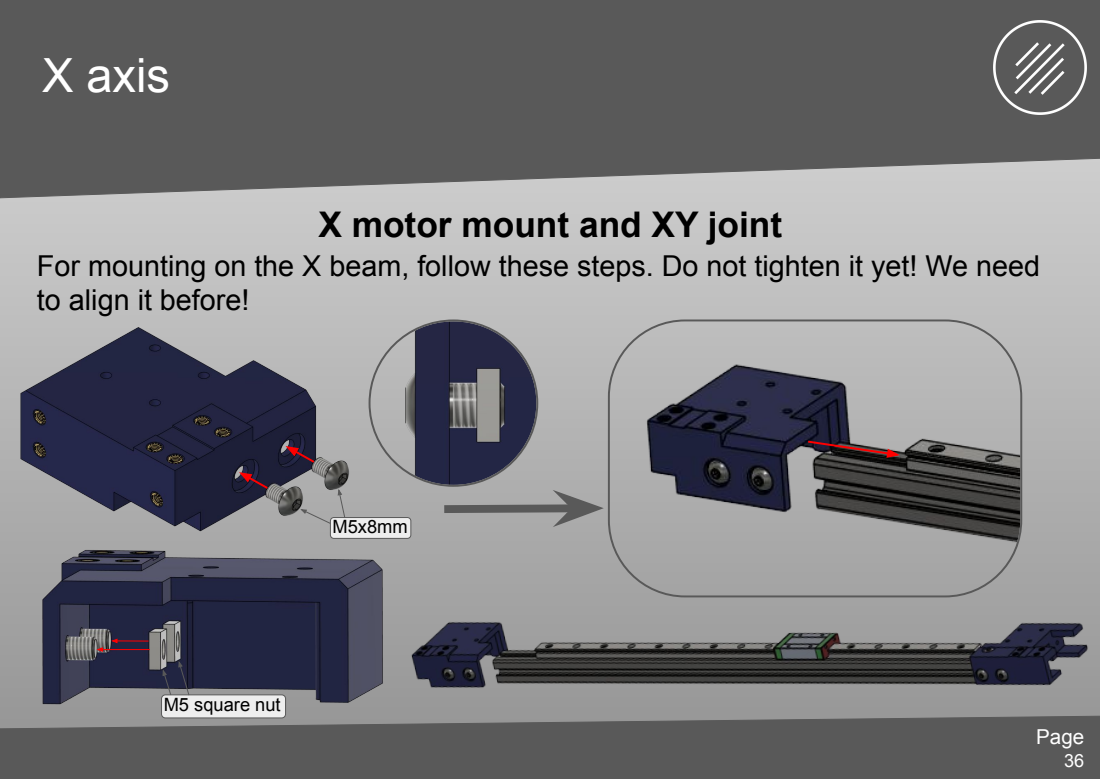
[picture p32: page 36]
M5 square nut

X motor mount and XY joint

For mounting on the X beam, follow these steps. Do not tighten it yet! We need
to align it before!

## X axis

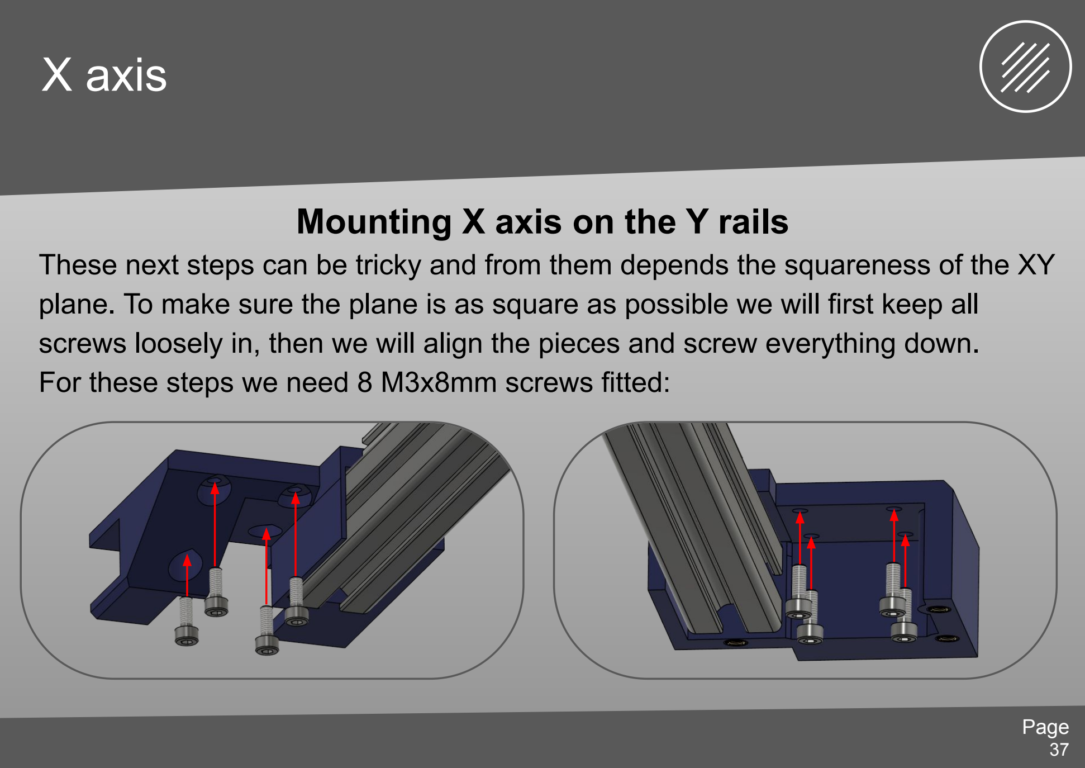
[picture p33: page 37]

### Mounting X axis on the Y rails

These next steps can be tricky and from them depends the squareness of the XY plane. To make sure the plane is as square as possible we will first keep all screws loosely in, then we will align the pieces and screw everything down.
For these steps we need 8 M3x8mm screws fitted:

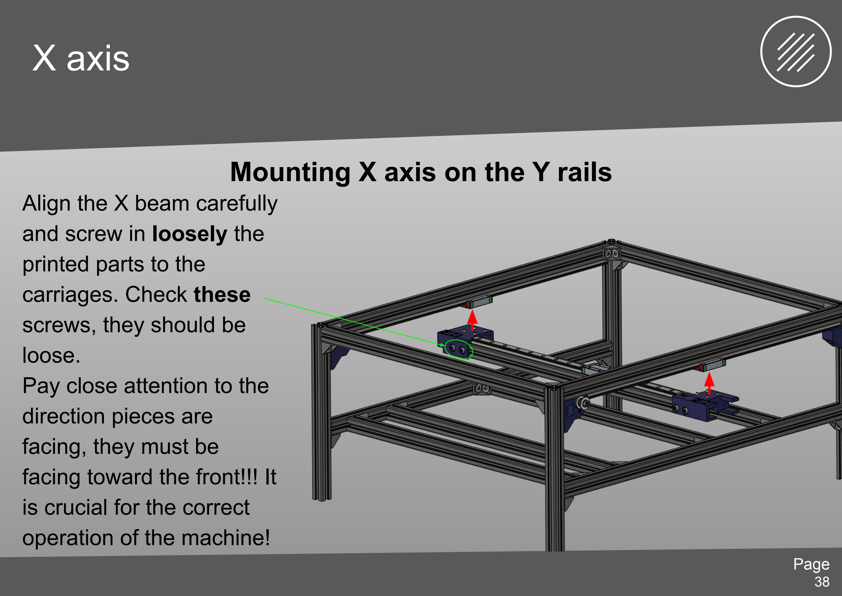
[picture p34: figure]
X axis; Mounting X axis on the Y rails; Align the X beam carefully and screw in loosely the printed parts to the carriages. Check these screws, they should be loose. Pay close attention to the direction pieces are facing, they must be facing toward the front!!! It is crucial for the correct operation of the machine!

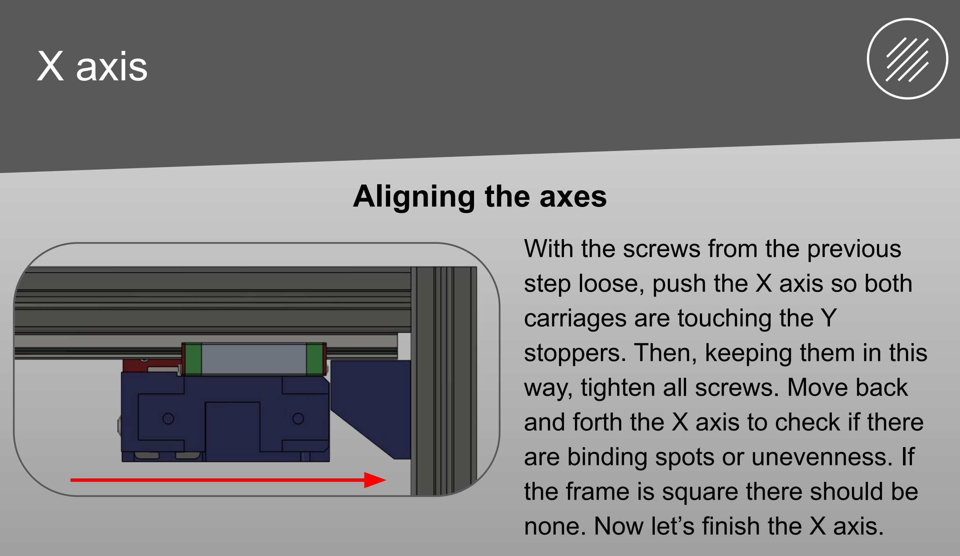
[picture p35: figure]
X axis; Aligning the axes; With the screws from the previous step loose, push the X axis so both carriages are touching the Y stoppers. Then, keeping them in this way, tighten all screws. Move back and forth the X axis to check if there are binding spots or unevenness. If the frame is square there should be none. Now let’s finish the X axis.

## X axis

X motor mount and XY joint

Fit the motor assembly as shown below, tighten all the screws and double check
all the connections.

## X axis

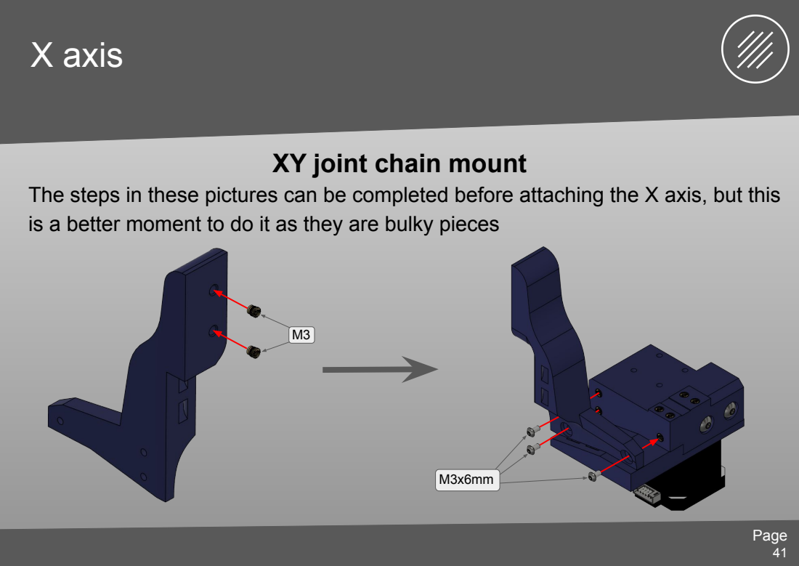
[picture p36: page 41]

XY joint chain mount

The steps in these pictures can be completed before attaching the X axis, but this
is a better moment to do it as they are bulky pieces

## Toolhead

### A word about naming

This section is called toolhead, because i come from the 3D printing world and this is the most familiar way to talk about it.
I just want to let you understand that with “toolhead” i mean the whole assembly where the two heads will be mounted, their linear rails and the Z motor.
This section is also relying on a “toolboard” PCB, a glorified connector board that allows easy unplugging of the toolhead from the main harness when needed. This allows you to make maintenance easier.
Modifications could be made to implement the same board on the XY joint if the request is loud enough.

## Toolhead

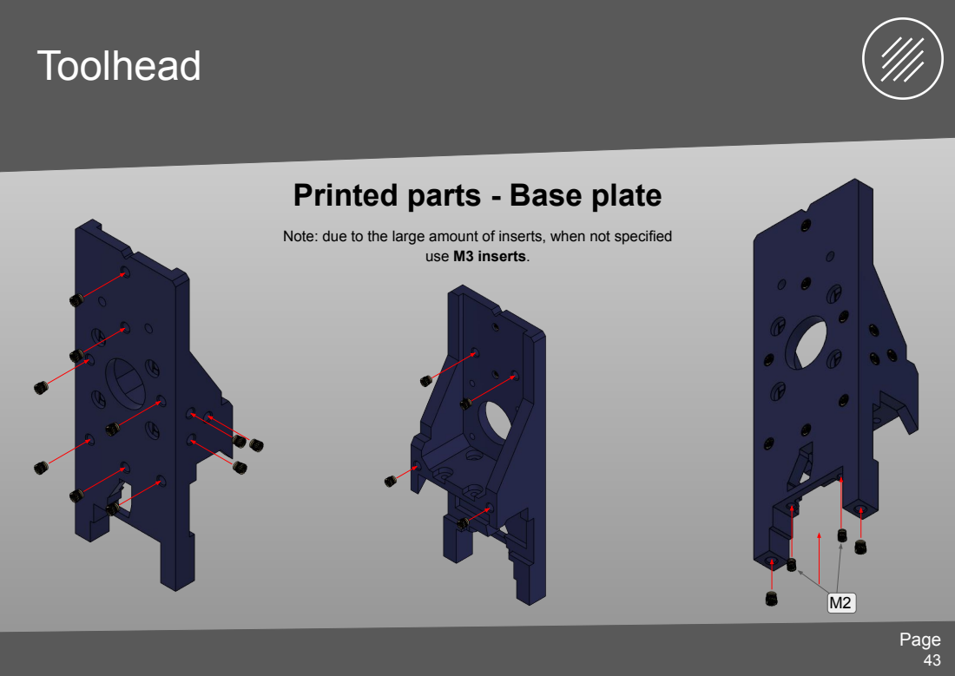
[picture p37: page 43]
use M3 inserts.

Printed parts - Base plate

Note: due to the large amount of inserts, when not specified

## Toolhead

Printed parts - Rear cover and camera pieces

Concerning the camera parts, we will use only two
screws right now, so keep this in mind.

Add tape if fit is not tight!

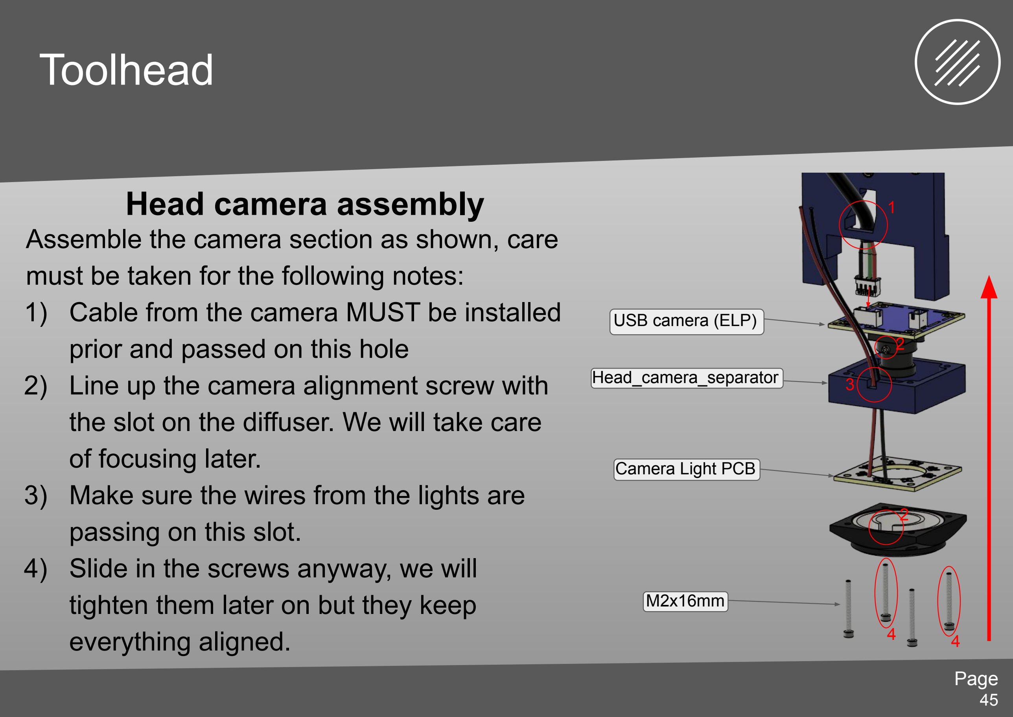
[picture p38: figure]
Toolhead; USB camera (ELP); Head_camera_separator; Camera Light PCB; Head camera assembly; must be taken for the following notes:; prior and passed on this hole; of focusing later.; passing on this slot. 4) Slide in the screws anyway, we will tighten them later on but they keep everything aligned.

Assemble the camera section as shown, care

1) Cable from the camera MUST be installed
2) Line up the camera alignment screw with the slot on the diffuser. We will take care
3) Make sure the wires from the lights are

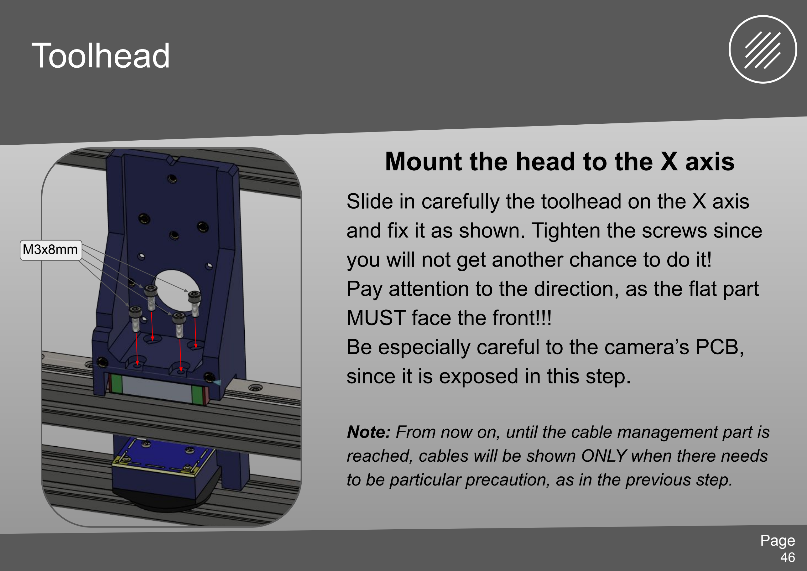
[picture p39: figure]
Toolhead; Mount the head to the X axis; MUST face the front!!!; since it is exposed in this step.

Slide in carefully the toolhead on the X axis and fix it as shown. Tighten the screws since you will not get another chance to do it!
Pay attention to the direction, as the flat part

Be especially careful to the camera’s PCB,

Note: From now on, until the cable management part is reached, cables will be shown ONLY when there needs to be particular precaution, as in the previous step.

## Toolhead

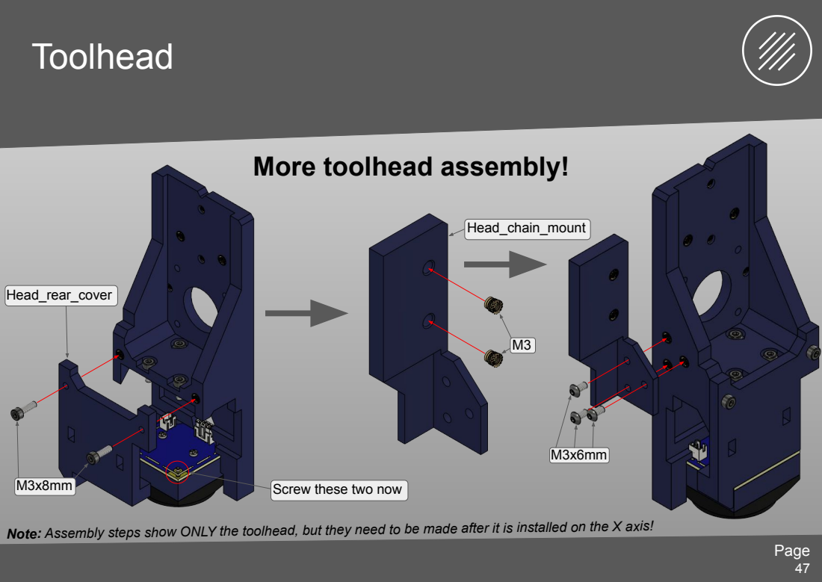
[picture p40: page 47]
Head_rear_cover; Screw these two now; Head_chain_mount

More toolhead assembly!

Note: Assembly steps show ONLY the toolhead, but they need to be made after it is installed on the X axis!

## Toolhead

…

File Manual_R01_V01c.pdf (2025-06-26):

# OrionPnP


Assembly manual

Rev.
01a 1

## Before we start…

### A word about safety

You are about to build a machine, powered by mains voltage, which could become DEADLY if not handled properly. Please consult a professional if you are unsure on how to proceed when the symbol is shown.
We are going to build a machine, capable of injuring you and/or others. There is no pride in getting hurt or worse, so be careful and always wear adequate protective gear when needed.
In the manual the symbol is used whenever special care is required. Make sure to read the manual before starting!

## A word about this project

### OrionPnP

The OrionPnP project has been conceived to bring good performance pick-and-place machines to makers, with solid and reliable operation, the project aims to handle 0402 components to empower makers and allow smaller boards to be manufactured. The heart of the project is the open source software OpenPNP (https://openpnp.org/) of course!
The project is open source, and as such every reference in this manual is made to a specific machine version. Mods, add-ons and other non official modifications will have their own guides, so follow those.
The source of each and every information is (and will always be) the Github repository. (https://github.com/TheIgorMC/orionPnP)
Go and check the project if you haven’t already, read the wiki and if this is the project for you, get ready to build!

## How to navigate this manual

### The manual

This manual will take you step by step from a bunch of components to a working OrionPnP machine. Each step is written as clearly as possible, but the drawings and the representations should clarify any doubt.
Minor differences might be noticeable but if the difference doesn’t affect the
assembly, the step is still valid. (e.g. toothed profile on belt holders might be different)
Several tools will be needed, and the list can be found in the BOM. 3D printed parts require no particular setting and can be printed in PLA, only motor mounts should be printed in heat resistant material as ABS, ASA or PETG.
Several screws will be used, make sure to reference the BOM for the codes relative to those. In the steps where different sizes will be used, a 1:1 scale image of the screws will be included as reference.
For this to be useful you must print it without scaling from the printer!

## Main frame

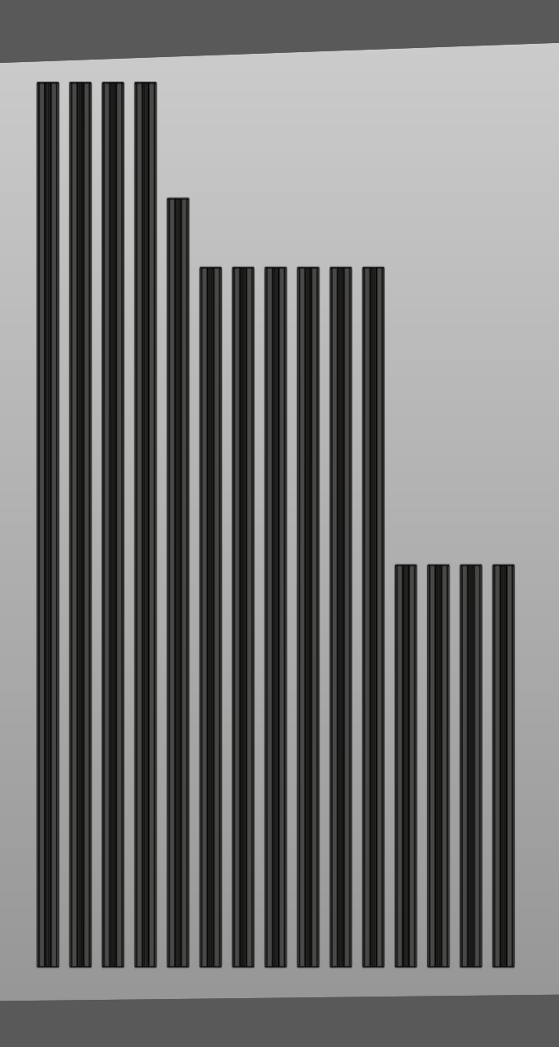
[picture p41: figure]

### Get the profiles ready

The machine is built around 2020 aluminium profiles, their sizes and amounts are:

All these profiles need to be prepared for the next step.
No drilling or tapping is required by design, but you can tap the ends and use screws to reinforce the connections if you really want to.
We will start the build by assembling the “bed”, where the work surface will go later on and the rest of the frame.
4x 250mm for the legs | 6x 435mm for the X axis and bracing
1x 478mm for the X axis itself | 4x 550mm for the Y axis

## Main frame

### Prepare corner brackets

Prepare the corner brackets as illustrated, using M4x8mm button head screws and a square nut. A washer is recommended.
In total we need 20 brackets prepared this way. Note: depending on your corner brackets you might also use M5x8mm screws.
Then prepare the 6x 435mm profiles as illustrated below. Do the same for 2x 550mm profiles. Only tighten screws on the profile side of the bracket. Leave the other nut loose!

As level as possible

Main frame; Assemble the bottom profiles; Take 4x of the 435mm profiles prepared earlier and 2x 550mm profiles.; as accurate as possible.; precise as possible. Pay attention to the orientation of the brackets!; very similar to this.

Place them as shown in the drawing, following the order, making sure the measurements are

It is not mandatory to be 0.1mm perfect, we will calibrate in software, but try to be as

Note: illustration is on scale so yours should look

## Main frame

Tap the legs of the frame

Take the 4 250mm profiles and tap one end with an M5 thread. This will be used
to fix the feet on them later on. Only about 6mm need to be threaded.

Main frame; profile.; them later.; parts.; Prepare top Y beams brackets; As level as possible

Take the other 2x 550mm profiles and add corner brackets as shown in the picture. Tighten only the section connected to the

Then keep them to the side as we will need

Now we will move on the first two 3D printed

## Main frame

Page

We will need the Y_Corner_idler_holder_R and Y_Corner_idler_holder_L files printed.
We will also need:
2x M3 heat set inserts
2x M5 heat set inserts
4x M5 square nuts
4x M5x10mm button head screws 2x M5x35mm cap head screws
2x Toothed GT2 idlers for 6mm belts

Steps will need to be done on both R and L pieces, they are symmetrical.

### Prepare the idler holders

## Main frame

Turn the piece 180°

M3

M5

Note: L idler holder shown in the pictures

Y_Corner_idler_holder

## Main frame

Add square nuts

Note: L idler holder shown in the pictures

## Main frame


Note: L idler holder shown in the pictures

M5x35mm

Idler

## Main frame


Assemble the top frame

Now take the 2x 550mm and 2x
435mm profiles prepared earlier and
assemble as shown. Be careful of the
orientations, and make sure the two
profiles on the edge are even like
shown.
Later the leg profiles will need to fit
here.

## Main frame

Mount the idler holders

If this bracket is in the
way, undo it and slide the
holder in, then realign it.

Note: L idler holder shown in the pictures

## Main frame

### Finished top frame

The top frame is now
finished, make sure it
looks like the picture
shown.
Do not worry at this point if it is not aligned, we will take care in the next steps about it.

## Main frame


Finished top frame

Take the 4x 250mm profiles and fix them to the top frame as shown.

Note: L idler holder shown

## Main frame

### Finish the frame

Now slide in the bottom frame as shown and screw the corner brackets to fix it, take care about the measurements referred
below.

120mm

## Main frame

### Square the frame

This is the time to square the frame. To do this lay the machine on the top frame, having care to check if there is any wobble.
Undo screws and fix all the profiles in their correct positions, making sure to measure the distances when needed.
If the frame is square, you should have all diagonals being equal (or close enough).
Once you are done, we can move on to the next section: rails!

## Y Axis rails

### Prepare the rails and fasteners

For this section, we will need 2x 500mm MGN12 linear rails to make the two Y axis rails. We need to clean them with some isopropyl alcohol to degrease them first! Remove the shuttles if you have the right holder for the carriage, otherwise leave it on!

Take care while removing the carriages to not losing the balls inside! There are plenty of tutorials on how to properly clean rails!

When clean, regrease it properly and get ready these fasteners:
- 20x M3x8mm Socket head screws
- 20x M3 hammer T-nut

## Y Axis rails

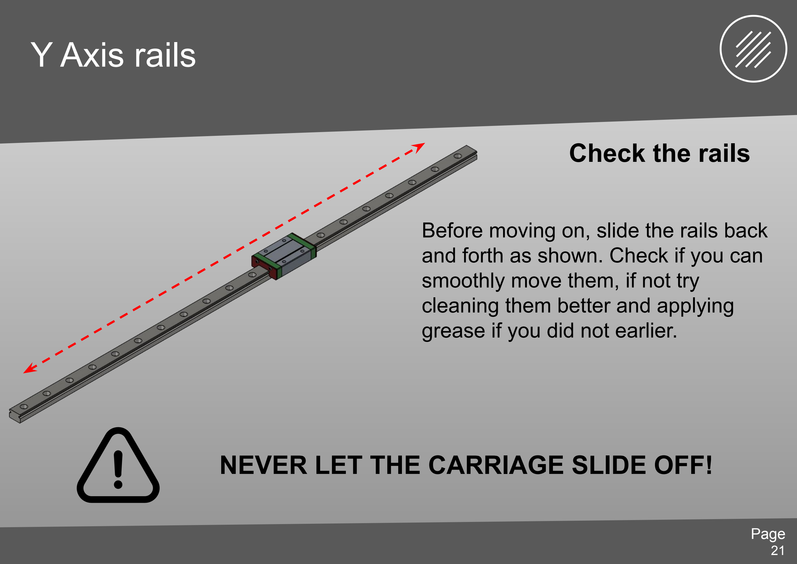
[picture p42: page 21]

### Check the rails

Before moving on, slide the rails back and forth as shown. Check if you can smoothly move them, if not try cleaning them better and applying grease if you did not earlier.

### NEVER LET THE CARRIAGE SLIDE OFF!

## Y Axis rails

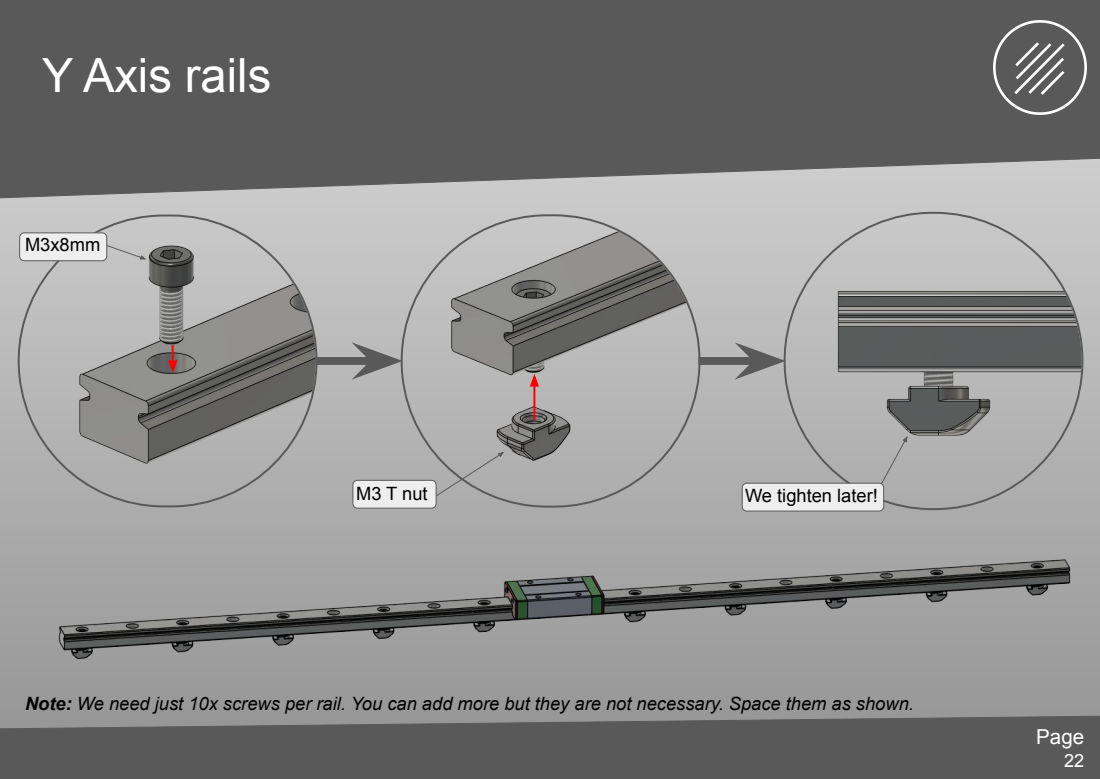
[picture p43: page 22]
M3 T nut; We tighten later!

Note: We need just 10x screws per rail. You can add more but they are not necessary. Space them as shown.

## Y Axis rails

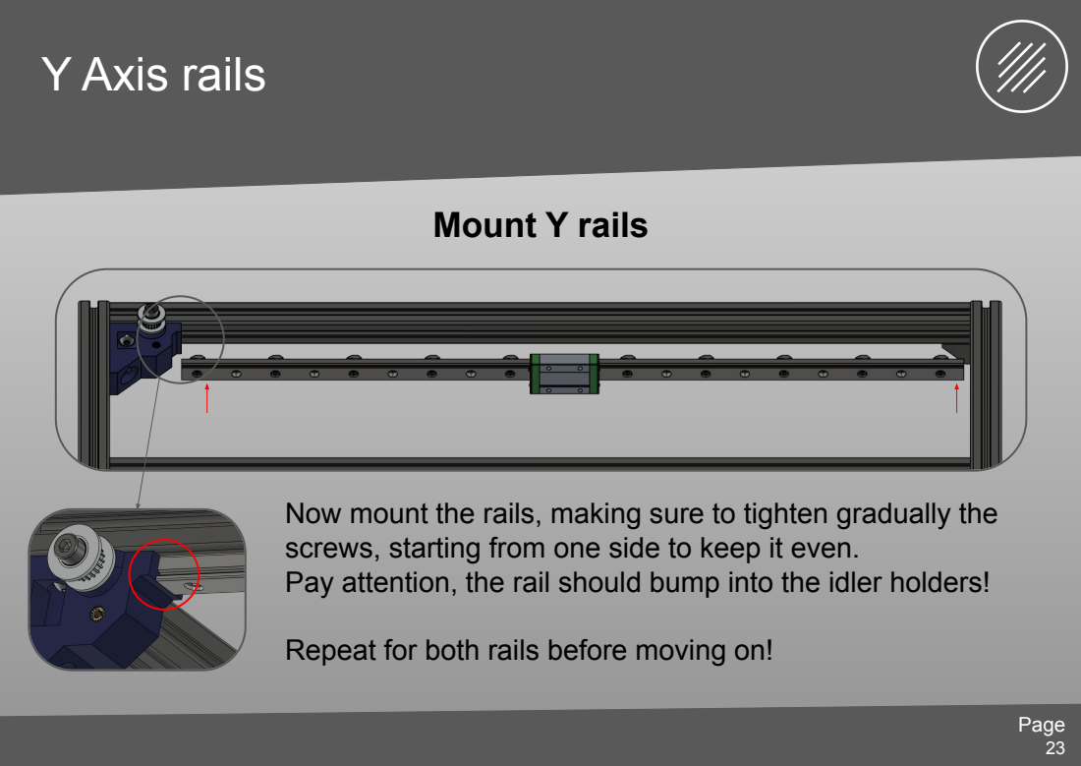
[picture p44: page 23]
Mount Y rails

Now mount the rails, making sure to tighten gradually the
screws, starting from one side to keep it even.
Pay attention, the rail should bump into the idler holders!

Repeat for both rails before moving on!

## Y Axis rails

We will mount the two Y stoppers now, needed to prevent the carriage from
falling out and to act as blocks for the Y axis.
Steps must be repeated on both Y axes.

## X axis

For the X axis we will need the 400mm MGN12 rail, once again we need to clean it from the oil and grease it as before:

Take care while removing the carriages to not losing the balls inside! There are plenty of tutorials on how to properly clean rails!

When clean, regrease it properly and get ready to assemble. We will need plenty of fasteners and printed parts, we will also need heat set inserts so be ready to get those in place too.
The printed parts list is in the X axis section, and the files start all with “X_” so you will need all of those.

### Prepare the rails and printed parts

## X axis

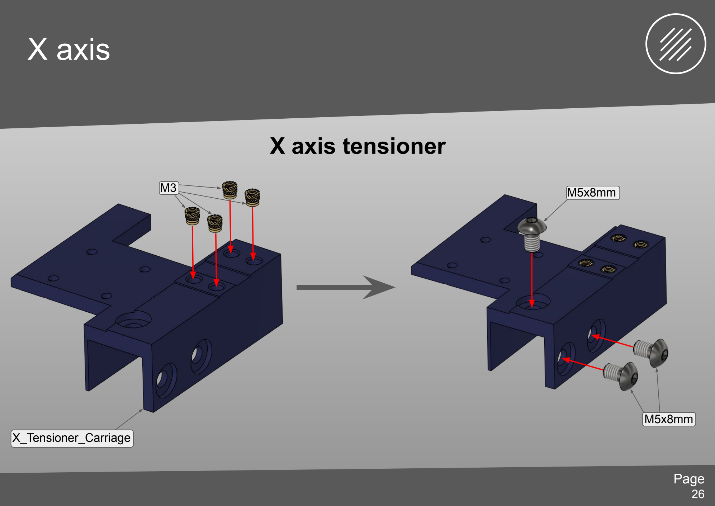
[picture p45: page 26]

### X axis tensioner

X_Tensioner_Carriage

M3

M5x8mm

M5x8mm

## X axis

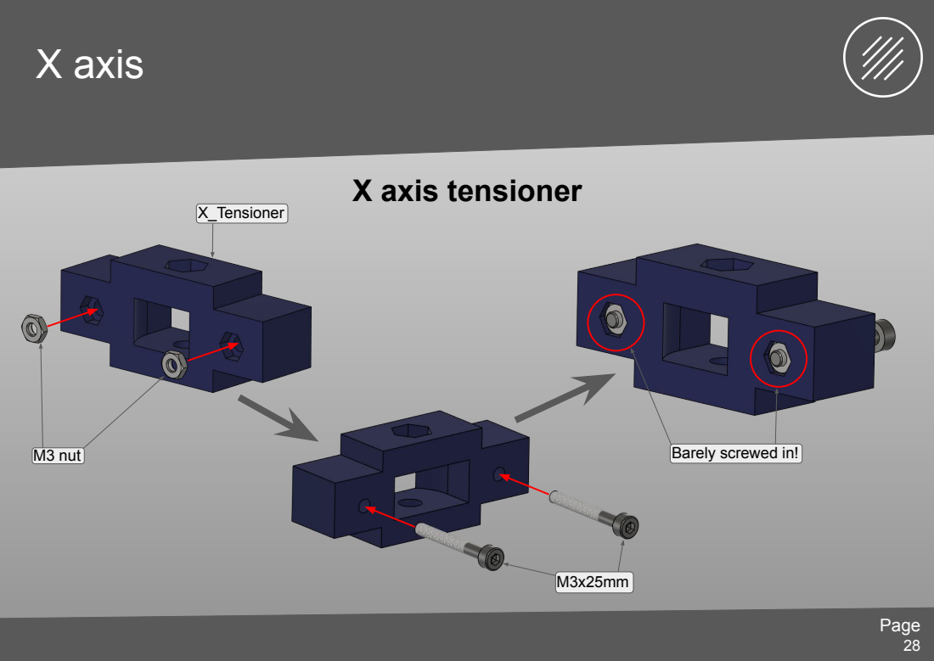
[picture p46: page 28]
X axis tensioner; M3 nut; X_Tensioner

Barely screwed in!

## X axis

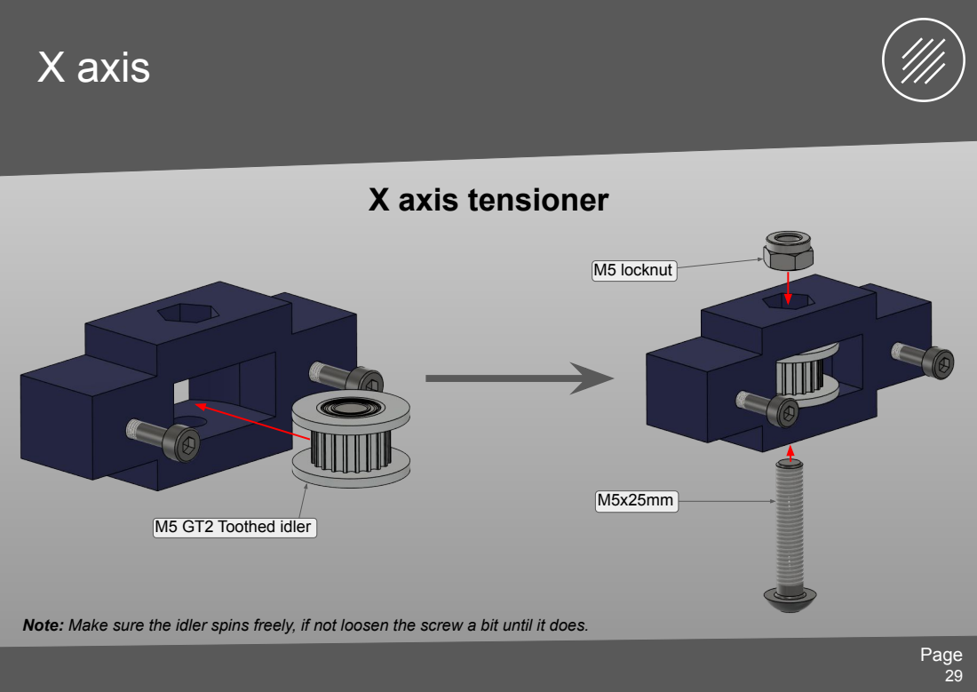
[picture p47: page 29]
X axis tensioner; M5 GT2 Toothed idler; M5 locknut

Note: Make sure the idler spins freely, if not loosen the screw a bit until it does.

## X axis

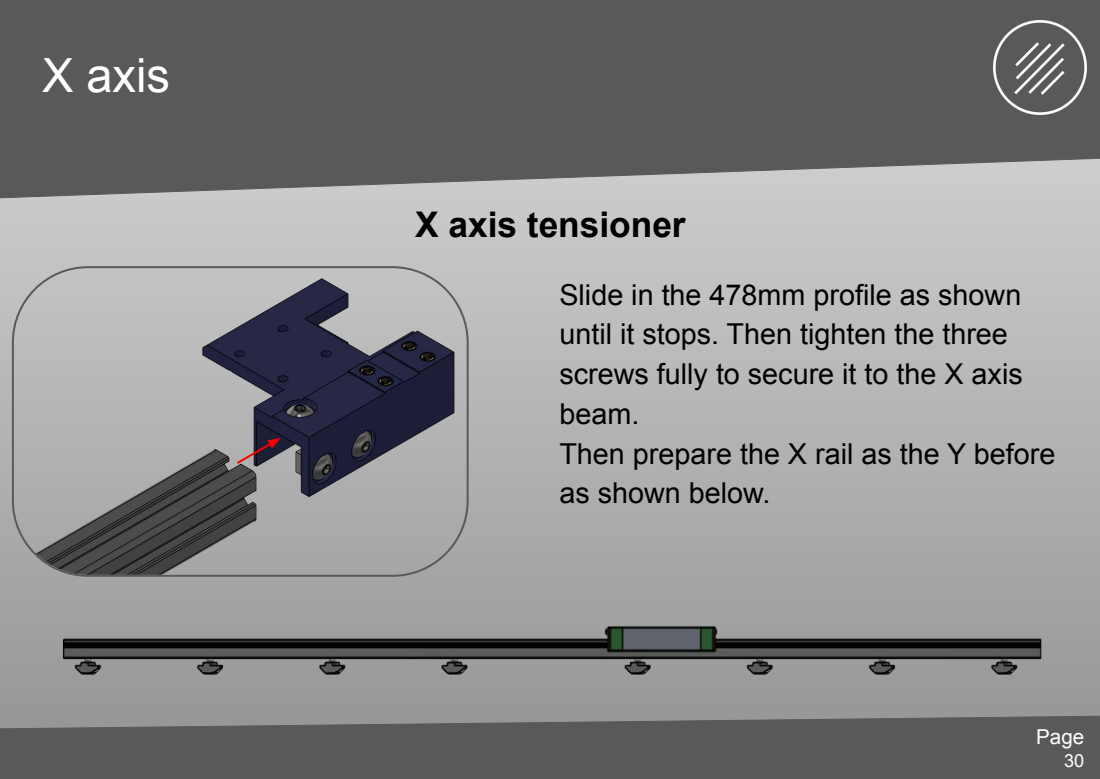
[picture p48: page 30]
X axis tensioner

Slide in the 478mm profile as shown
until it stops. Then tighten the three
screws fully to secure it to the X axis
beam.
Then prepare the X rail as the Y before
as shown below.

## X axis

X motor mount and XY joint

## X axis

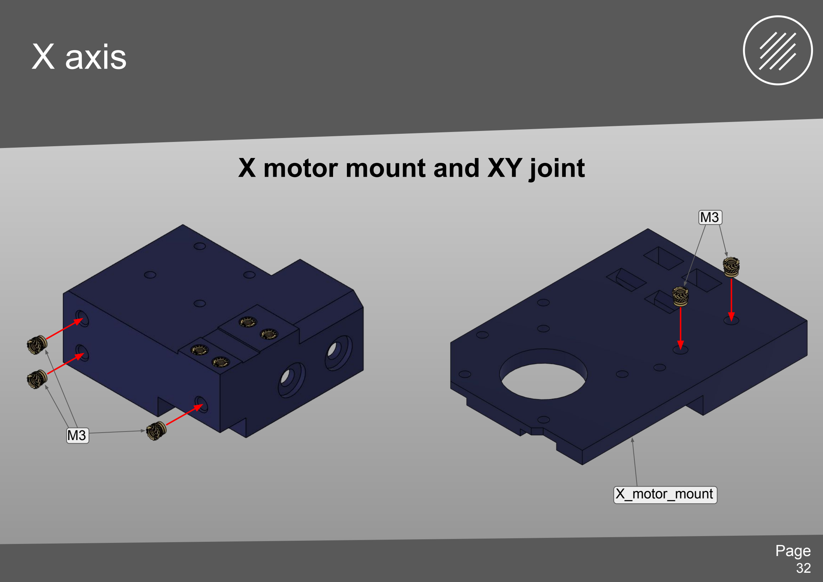
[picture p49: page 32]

### X motor mount and XY joint

M3

X_motor_mount

M3

## X axis

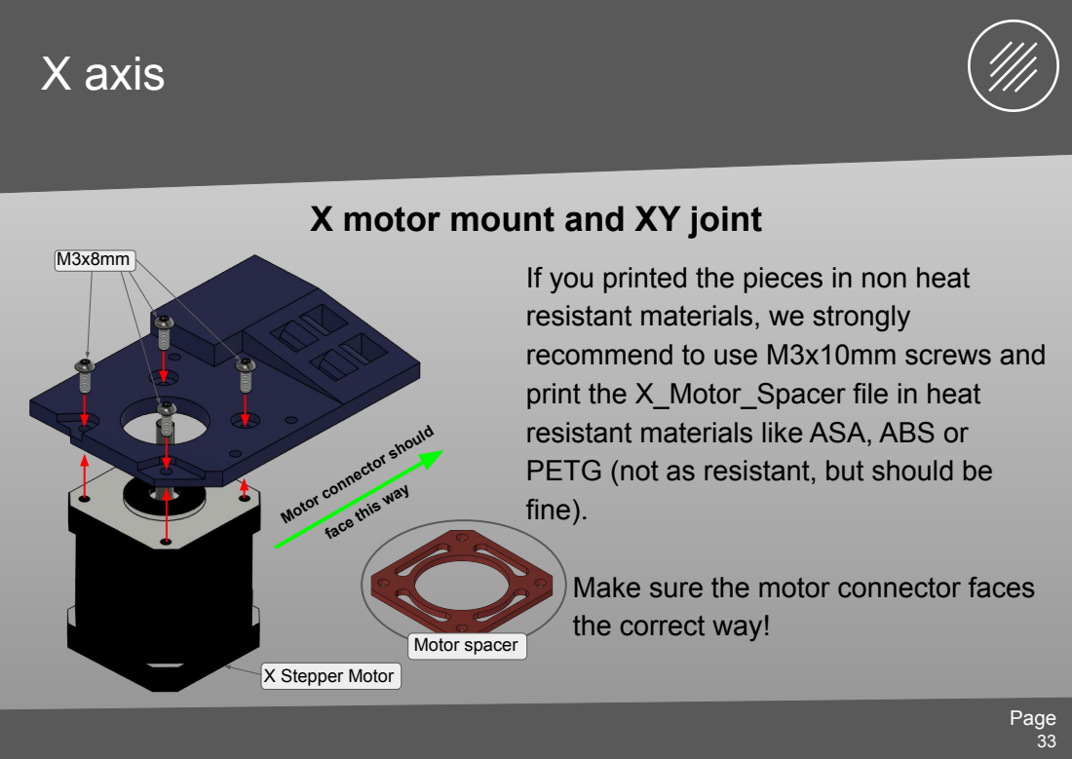
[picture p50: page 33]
X Stepper Motor; Motor spacer

X motor mount and XY joint

If you printed the pieces in non heat
resistant materials, we strongly
recommend to use M3x10mm screws and
print the X_Motor_Spacer file in heat
resistant materials like ASA, ABS or
PETG (not as resistant, but should be
fine).

Motor connector should

face this way

Make sure the motor connector faces
the correct way!

## X axis

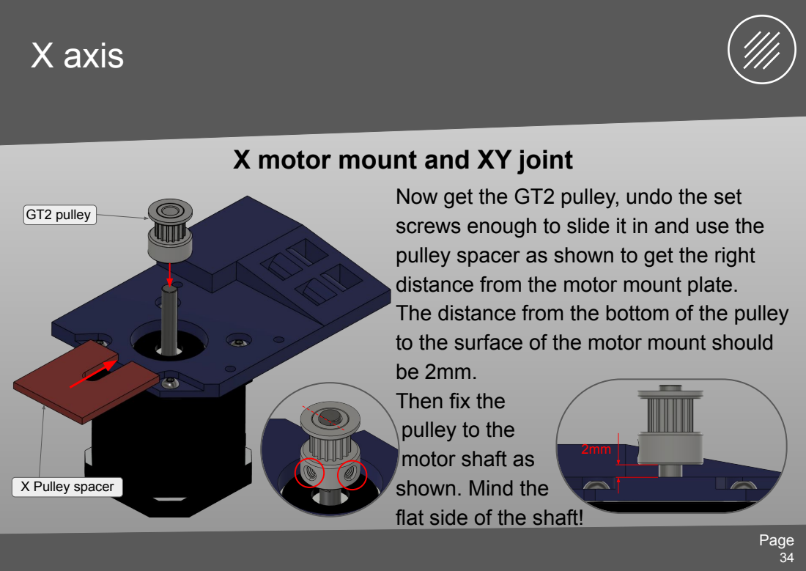
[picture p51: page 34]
GT2 pulley; X Pulley spacer

X motor mount and XY joint

Now get the GT2 pulley, undo the set
screws enough to slide it in and use the
pulley spacer as shown to get the right
distance from the motor mount plate.
The distance from the bottom of the pulley
to the surface of the motor mount should
Then fix the
pulley to the
motor shaft as
shown. Mind the
flat side of the shaft!

## X axis

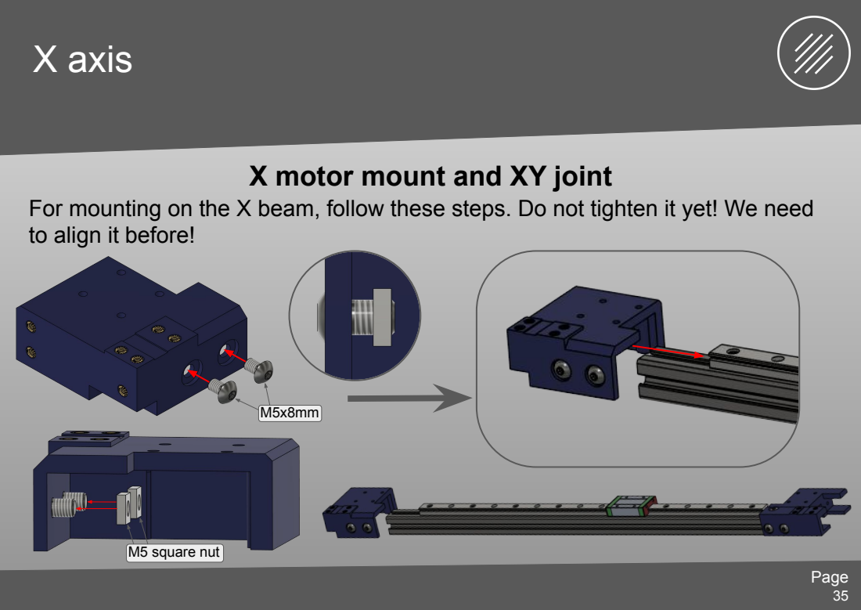
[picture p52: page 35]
M5 square nut

X motor mount and XY joint

For mounting on the X beam, follow these steps. Do not tighten it yet! We need
to align it before!

## X axis

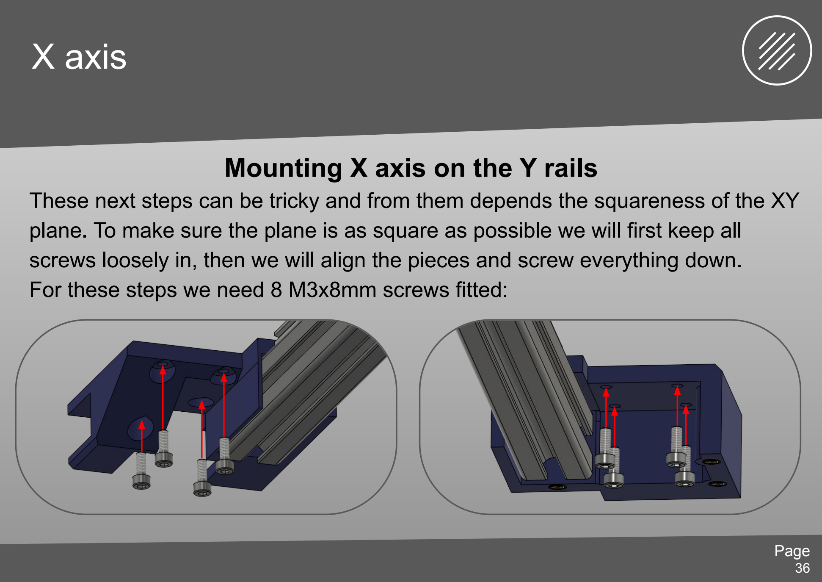
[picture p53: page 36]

### Mounting X axis on the Y rails

These next steps can be tricky and from them depends the squareness of the XY plane. To make sure the plane is as square as possible we will first keep all screws loosely in, then we will align the pieces and screw everything down.
For these steps we need 8 M3x8mm screws fitted:

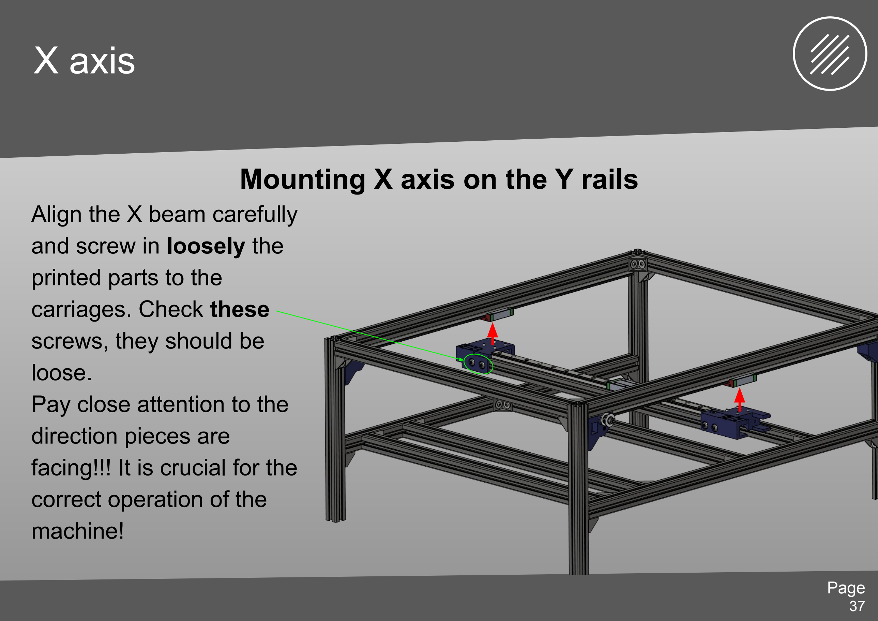
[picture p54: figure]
X axis; Mounting X axis on the Y rails; Align the X beam carefully and screw in loosely the printed parts to the carriages. Check these screws, they should be loose. Pay close attention to the direction pieces are facing!!! It is crucial for the correct operation of the machine!

X axis; Aligning the axes; With the screws from the previous step loose, push the X axis so both carriages are touching the Y stoppers. Then, keeping them in this way, tighten all screws. Move back and forth the X axis to check if there are binding spots or unevenness. If the frame is square there should be none. Now let’s finish the X axis.

## X axis

X motor mount and XY joint

Fit the motor assembly as shown below, tighten all the screws and double check
all the connections.

## X axis

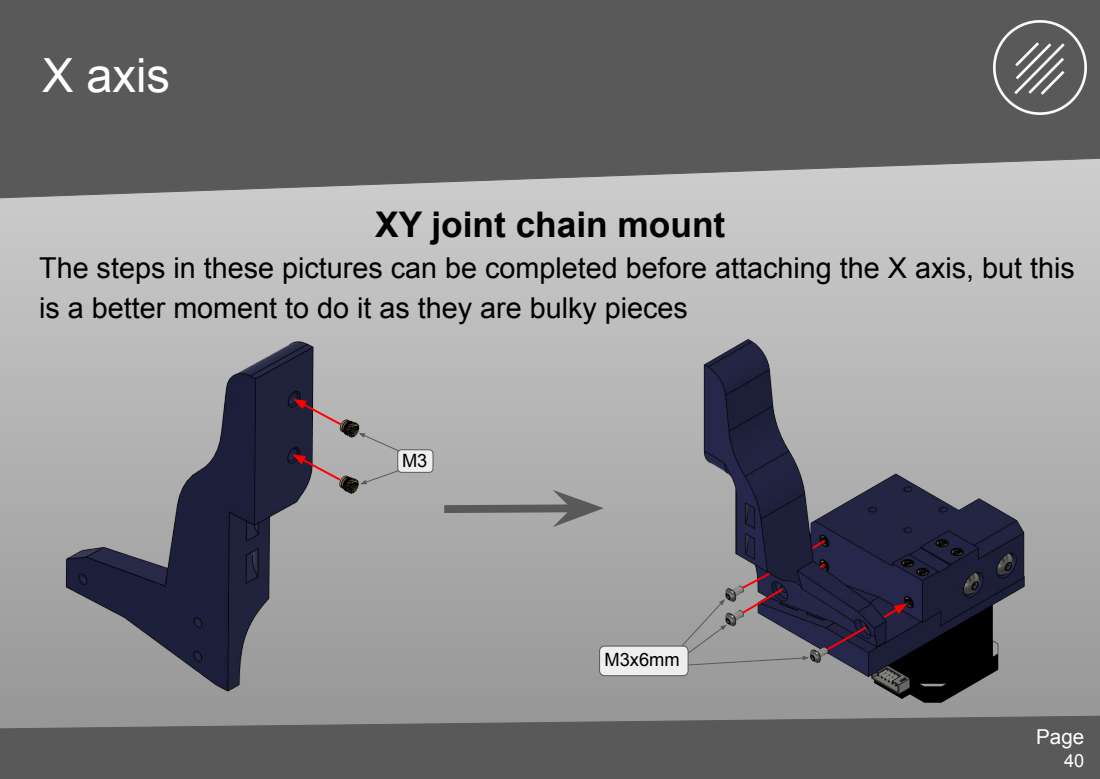
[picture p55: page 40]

XY joint chain mount

The steps in these pictures can be completed before attaching the X axis, but this
is a better moment to do it as they are bulky pieces

## Toolhead

### A word about naming

This section is called toolhead, because i come from the 3D printing world and this is the most familiar way to talk about it.
I just want to let you understand that with “toolhead” i mean the whole assembly where the two heads will be mounted, their linear rails and the Z motor.
This section is also relying on a “toolboard” PCB, a glorified connector board that allows easy unplugging of the toolhead from the main harness when needed. This allows you to make maintenance easier.
Modifications could be made to implement the same board on the XY joint if the request is loud enough.

## Toolhead

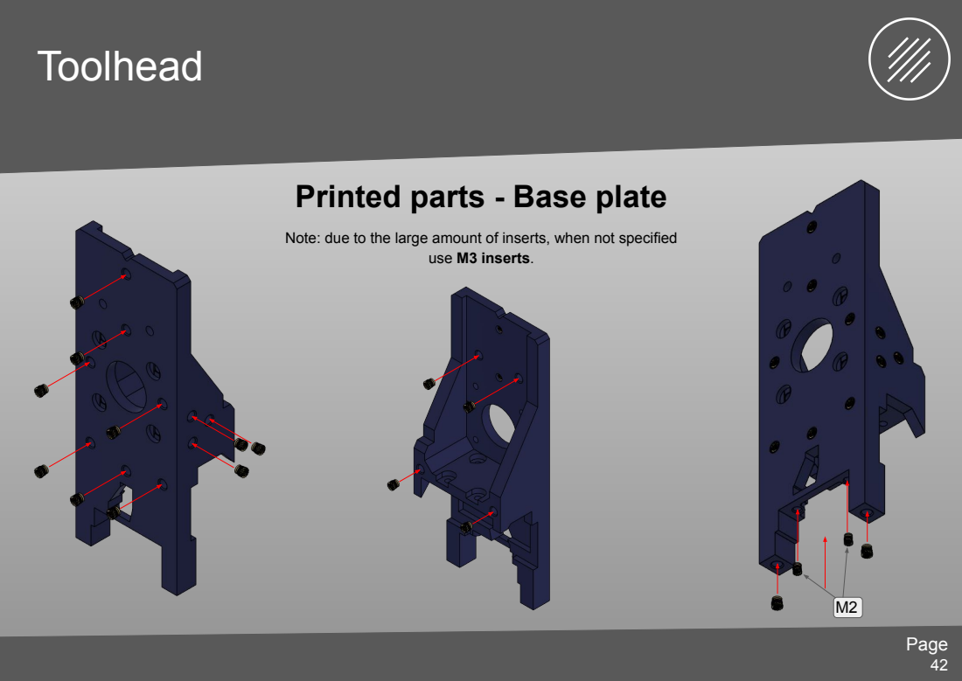
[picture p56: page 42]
use M3 inserts.

Printed parts - Base plate

Note: due to the large amount of inserts, when not specified

Toolhead

### Printed parts - Rear cover and camera pieces

## Toolhead

…

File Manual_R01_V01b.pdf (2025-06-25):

# OrionPnP


Assembly manual

Rev.
01a 1

## Before we start…

### A word about safety


You are about to build a machine, powered by mains voltage, which could become DEADLY if not handled properly. Please consult a professional if you are unsure on how to proceed when the symbol is shown.
We are going to build a machine, capable of injuring you and/or others. There is no pride in getting hurt or worse, so be careful and always wear adequate protective gear when needed.
In the manual the symbol is used whenever special care is required. Make sure to read the manual before starting!

## A word about this project

### OrionPnP

The OrionPnP project has been conceived to bring good performance pick-and-place machines to makers, with solid and reliable operation, the project aims to handle 0402 components to empower makers and allow smaller boards to be manufactured. The heart of the project is the open source software OpenPNP (https://openpnp.org/) of course!
The project is open source, and as such every reference in this manual is made to a specific machine version. Mods, add-ons and other non official modifications will have their own guides, so follow those.
The source of each and every information is (and will always be) the Github repository. (https://github.com/TheIgorMC/orionPnP)
Go and check the project if you haven’t already, read the wiki and if this is the project for you, get ready to build!

## How to navigate this manual

### The manual

This manual will take you step by step from a bunch of components to a working OrionPnP machine. Each step is written as clearly as possible, but the drawings and the representations should clarify any doubt.
Minor differences might be noticeable but if the difference doesn’t affect the
assembly, the step is still valid. (e.g. toothed profile on belt holders might be different)
Several tools will be needed, and the list can be found in the BOM. 3D printed parts require no particular setting and can be printed in PLA, only motor mounts should be printed in heat resistant material as ABS, ASA or PETG.
Several screws will be used, make sure to reference the BOM for the codes relative to those. In the steps where different sizes will be used, a 1:1 scale image of the screws will be included as reference.
For this to be useful you must print it without scaling from the printer!

## Main frame

### Get the profiles ready

The machine is built around 2020 aluminium profiles, their sizes and amounts are:

All these profiles need to be prepared for the next step.
No drilling or tapping is required by design, but you can tap the ends and use screws to reinforce the connections if you really want to.
We will start the build by assembling the “bed”, where the work surface will go later on and the rest of the frame.
4x 250mm for the legs | 6x 435mm for the X axis and bracing
1x 478mm for the X axis itself | 4x 550mm for the Y axis

## Main frame


### Prepare corner brackets

Prepare the corner brackets as illustrated, using M4x8mm button head screws and a square nut. A washer is recommended.
In total we need 20 brackets prepared this way. Note: depending on your corner brackets you might also use M5x8mm screws.
Then prepare the 6x 435mm profiles as illustrated below. Do the same for 2x 550mm profiles. Only tighten screws on the profile side of the bracket. Leave the other nut loose!

As level as possible

Main frame; Assemble the bottom profiles; Take 4x of the 435mm profiles prepared earlier and 2x 550mm profiles.; as accurate as possible.; precise as possible. Pay attention to the orientation of the brackets!; very similar to this.

Place them as shown in the drawing, following the order, making sure the measurements are

It is not mandatory to be 0.1mm perfect, we will calibrate in software, but try to be as

Note: illustration is on scale so yours should look

## Main frame

Tap the legs of the frame

Take the 4 250mm profiles and tap one end with an M5 thread. This will be used
to fix the feet on them later on. Only about 6mm need to be threaded.

Main frame; profile.; them later.; parts.; Prepare top Y beams brackets; As level as possible

Take the other 2x 550mm profiles and add corner brackets as shown in the picture. Tighten only the section connected to the

Then keep them to the side as we will need

Now we will move on the first two 3D printed

## Main frame

Page

We will need the Y_Corner_idler_holder_R and Y_Corner_idler_holder_L files printed.
We will also need:
2x M3 heat set inserts
2x M5 heat set inserts
4x M5 square nuts
4x M5x10mm button head screws 2x M5x35mm cap head screws
2x Toothed GT2 idlers for 6mm belts

Steps will need to be done on both R and L pieces, they are symmetrical.

### Prepare the idler holders

## Main frame

Turn the piece 180°

M3

M5

Note: L idler holder shown in the pictures

Y_Corner_idler_holder

## Main frame

Add square nuts

Note: L idler holder shown in the pictures

## Main frame


Note: L idler holder shown in the pictures

M5x35mm

Idler

## Main frame


Assemble the top frame

Now take the 2x 550mm and 2x
435mm profiles prepared earlier and
assemble as shown. Be careful of the
orientations, and make sure the two
profiles on the edge are even like
shown.
Later the leg profiles will need to fit
here.

## Main frame


Mount the idler holders

If this bracket is in the
way, undo it and slide the
holder in, then realign it.

Note: L idler holder shown in the pictures

## Main frame

### Finished top frame

The top frame is now
finished, make sure it
looks like the picture
shown.
Do not worry at this point if it is not aligned, we will take care in the next steps about it.

## Main frame


Finished top frame

Take the 4x 250mm profiles and fix them to the top frame as shown.

Note: L idler holder shown

## Main frame


### Finish the frame

Now slide in the bottom frame as shown and screw the corner brackets to fix it, take care about the measurements referred
below.

120mm

## Main frame

### Square the frame

This is the time to square the frame. To do this lay the machine on the top frame, having care to check if there is any wobble.
Undo screws and fix all the profiles in their correct positions, making sure to measure the distances when needed.
If the frame is square, you should have all diagonals being equal (or close enough).
Once you are done, we can move on to the next section: rails!

## Y Axis rails

### Prepare the rails and fasteners

For this section, we will need 2x 500mm MGN12 linear rails to make the two Y axis rails. We need to clean them with some isopropyl alcohol to degrease them first! Remove the shuttles if you have the right holder for the carriage, otherwise leave it on!

Take care while removing the carriages to not losing the balls inside! There are plenty of tutorials on how to properly clean rails!

When clean, regrease it properly and get ready these fasteners:
- 20x M3x8mm Socket head screws
- 20x M3 hammer T-nut

## Y Axis rails

### Check the rails

Before moving on, slide the rails back and forth as shown. Check if you can smoothly move them, if not try cleaning them better and applying grease if you did not earlier.

### NEVER LET THE CARRIAGE SLIDE OFF!

## Y Axis rails

M3 T nut; We tighten later!

Note: We need just 10x screws per rail. You can add more but they are not necessary. Space them as shown.

## Y Axis rails

Mount Y rails

Now mount the rails, making sure to tighten gradually the
screws, starting from one side to keep it even.
Pay attention, the rail should bump into the idler holders!

Repeat for both rails before moving on!

## Y Axis rails

Mount Y stoppers; M5x10mm Y_stopper

We will mount the two Y stoppers now, needed to prevent the carriage from
falling out and to act as blocks for the Y axis.
Steps must be repeated on both Y axes.

## X axis

For the X axis we will need the 400mm MGN12 rail, once again we need to clean it from the oil and grease it as before:

Take care while removing the carriages to not losing the balls inside! There are plenty of tutorials on how to properly clean rails!

When clean, regrease it properly and get ready to assemble. We will need plenty of fasteners and printed parts, we will also need heat set inserts so be ready to get those in place too.
The printed parts list is in the X axis section, and the files start all with “X_” so you will need all of those.

### Prepare the rails and printed parts

## X axis


### X axis tensioner

X_Tensioner_Carriage

M3

M5x8mm

M5x8mm

X axis; X axis tensioner; When adding the nuts, make sure to NOT tighten them but leave them as shown. It will be needed for sliding in the profile later on.; M5 square nut

## X axis

Barely screwed in!

## X axis

X axis tensioner; M5 GT2 Toothed idler; M5 locknut

Note: Make sure the idler spins freely, if not loosen the screw a bit until it does.

## X axis

X axis tensioner

Slide in the 478mm profile as shown
until it stops. Then tighten the three
screws fully to secure it to the X axis
beam.
Then prepare the X rail as the Y before
as shown below.

## X axis


X motor mount and XY joint

## X axis


### X motor mount and XY joint

M3

X_motor_mount

M3

## X axis

X Stepper Motor; Motor spacer

X motor mount and XY joint

If you printed the pieces in non heat
resistant materials, we strongly
recommend to use M3x10mm screws and
print the X_Motor_Spacer file in heat
resistant materials like ASA, ABS or
PETG (not as resistant, but should be
fine).

Motor connector should

face this way

Make sure the motor connector faces
the correct way!

## X axis

GT2 pulley; X Pulley spacer

X motor mount and XY joint

Now get the GT2 pulley, undo the set
screws enough to slide it in and use the
pulley spacer as shown to get the right
distance from the motor mount plate.
The distance from the bottom of the pulley
to the surface of the motor mount should
Then fix the
pulley to the
motor shaft as
shown. Mind the
flat side of the shaft!

## X axis

M5 square nut

X motor mount and XY joint

For mounting on the X beam, follow these steps. Do not tighten it yet! We need
to align it before!

## X axis


### Mounting X axis on the Y rails

These next steps can be tricky and from them depends the squareness of the XY plane. To make sure the plane is as square as possible we will first keep all screws loosely in, then we will align the pieces and screw everything down.
For these steps we need 8 M3x8mm screws fitted:

X axis; Mounting X axis on the Y rails; Align the X beam carefully and screw in loosely the printed parts to the carriages. Check these screws, they should be loose. Pay close attention to the direction pieces are facing!!! It is crucial for the correct operation of the machine!

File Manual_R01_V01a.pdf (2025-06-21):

# OrionPnP


Assembly manual

Rev.
01a 1

## Before we start…

### A word about safety


You are about to build a machine, powered by mains voltage, which could become DEADLY if not handled properly. Please consult a professional if you are unsure on how to proceed when the symbol is shown.
We are going to build a machine, capable of injuring you and/or others. There is no pride in getting hurt or worse, so be careful and always wear adequate protective gear when needed.
In the manual the symbol is used whenever special care is required. Make sure to read the manual before starting!

## A word about this project

### OrionPnP

The OrionPnP project has been conceived to bring good performance pick-and-place machines to makers, with solid and reliable operation, the project aims to handle 0402 components to empower makers and allow smaller boards to be manufactured. The heart of the project is the open source software OpenPNP (https://openpnp.org/) of course!
The project is open source, and as such every reference in this manual is made to a specific machine version. Mods, add-ons and other non official modifications will have their own guides, so follow those.
The source of each and every information is (and will always be) the Github repository. (https://github.com/TheIgorMC/orionPnP)
Go and check the project if you haven’t already, read the wiki and if this is the project for you, get ready to build!

## How to navigate this manual

### The manual

This manual will take you step by step from a bunch of components to a working OrionPnP machine. Each step is written as clearly as possible, but the drawings and the representations should clarify any doubt.
Several tools will be needed, and the list can be found in the BOM. 3D printed parts require no particular setting and can be printed in PLA, only motor mounts should be printed in heat resistant material as ABS, ASA or PETG.
Several screws will be used, make sure to reference the BOM for the codes relative to those. In the steps where different sizes will be used, a 1:1 scale image of the screws will be included as reference.
For this to be useful you must print it without scaling from the printer!

## Main frame


### Get the profiles ready

The machine is built around 2020 aluminium profiles, their sizes and amounts are:

All these profiles need to be prepared for the next step.
No drilling or tapping is required by design, but you can tap the ends and use screws to reinforce the connections if you really want to.
We will start the build by assembling the “bed”, where the work surface will go later on and the rest of the frame.
4x 250mm for the legs | 6x 435mm for the X axis and bracing
1x 478mm for the X axis itself | 4x 550mm for the Y axis

## Main frame


### Prepare corner brackets

Prepare the corner brackets as illustrated, using M4x8mm button head screws and a square nut. A washer is recommended.
In total we need 20 brackets prepared this way. Note: depending on your corner brackets you might also use M5x8mm screws.
Then prepare the 6x 435mm profiles as illustrated below. Do the same for 2x 550mm profiles. Only tighten screws on the profile side of the bracket. Leave the other nut loose!

As level as possible

Main frame; Assemble the bottom profiles; Take 4x of the 435mm profiles prepared earlier and 2x 550mm profiles.; as accurate as possible.; precise as possible. Pay attention to the orientation of the brackets!; very similar to this.

Place them as shown in the drawing, following the order, making sure the measurements are

It is not mandatory to be 0.1mm perfect, we will calibrate in software, but try to be as

Note: illustration is on scale so yours should look

Main frame; profile.; them later.; parts.; Prepare top Y beams brackets; As level as possible

Take the other 2x 550mm profiles and add corner brackets as shown in the picture. Tighten only the section connected to the

Then keep them to the side as we will need

Now we will move on the first two 3D printed

## Main frame

We will need the Y_Corner_idler_holder_R and Y_Corner_idler_holder_L files printed.
We will also need:
2x M3 heat set inserts
2x M5 heat set inserts
4x M5 square nuts
4x M5x10mm button head screws 2x M5x35mm cap head screws
2x Toothed GT2 idlers for 6mm belts

Steps will need to be done on both R and L pieces, they are symmetrical.

### Prepare the idler holders

## Main frame


Page

Turn the piece 180°

M3

M5

Note: L idler holder shown in the pictures

## Main frame

(leave loose); M5 square nut

Add square nuts

Note: L idler holder shown in the pictures

## Main frame


Note: L idler holder shown in the pictures

M5x35mm

Idler

## Main frame


Assemble the top frame

Now take the 2x 550mm and 2x
435mm profiles prepared earlier and
assemble as shown. Be careful of the
orientations, and make sure the two
profiles on the edge are even like
shown.
Later the leg profiles will need to fit
here.

## Main frame


Mount the idler holders

If this bracket is in the
way, undo it and slide the
holder in, then realign it.

Note: L idler holder shown in the pictures

## Main frame

### Finished top frame


The top frame is now
finished, make sure it
looks like the picture
shown.
Do not worry at this point if it is not aligned, we will take care in the next steps about it.

## Main frame


Finished top frame

Take the 4x 250mm profiles and fix them to the top frame as shown.

## Main frame


### Finish the frame

Now slide in the bottom frame as shown and screw the corner brackets to fix it, take care about the measurements referred
below.

120mm

## Main frame

### Square the frame

This is the time to square the frame. To do this lay the machine on the top frame, having care to check if there is any wobble.
Undo screws and fix all the profiles in their correct positions, making sure to measure the distances when needed.
If the frame is square, you should have all diagonals being equal (or close enough).
Once you are done, we can move on to the next section: rails!

## Y Axis rails

## Y Axis rails

## Y Axis rails

## Y Axis rails

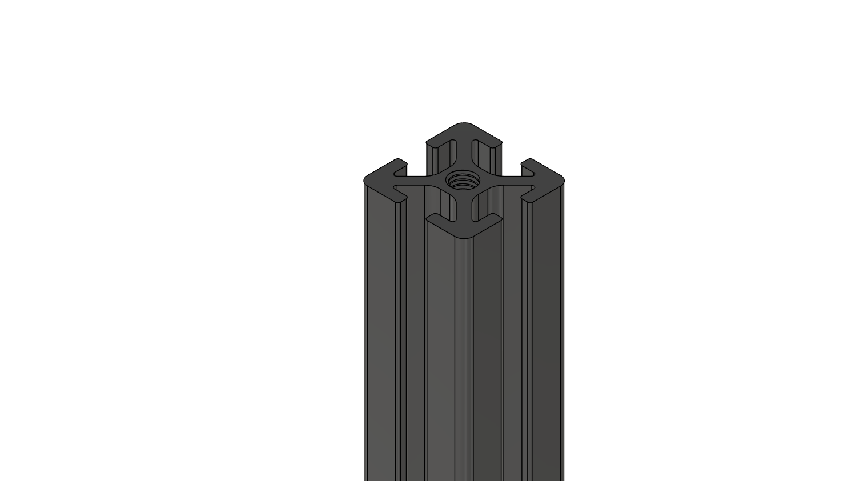
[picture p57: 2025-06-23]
assets/Assembly Manual R01/026 - Tap leg after.png

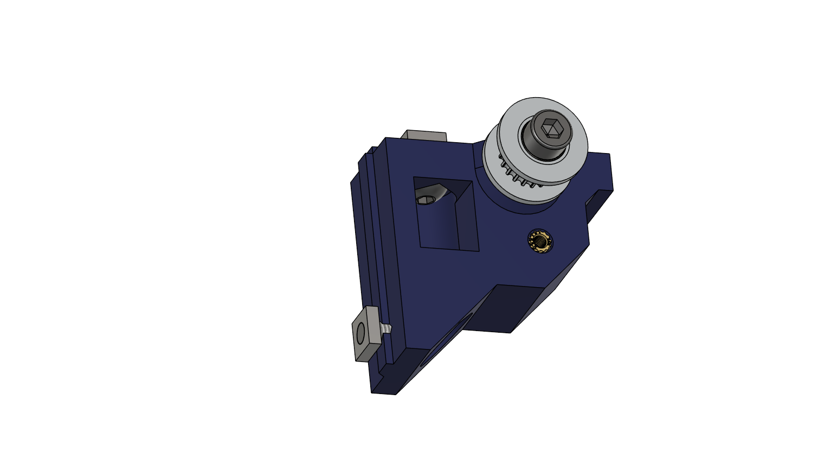
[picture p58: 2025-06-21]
assets/Assembly Manual R01/013 - Corner Idler Y g.png

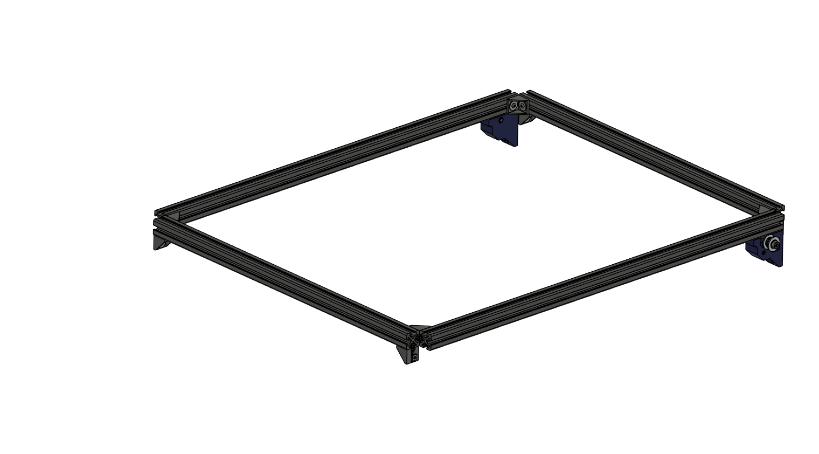
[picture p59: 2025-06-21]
assets/Assembly Manual R01/019 - Top frame finished.png

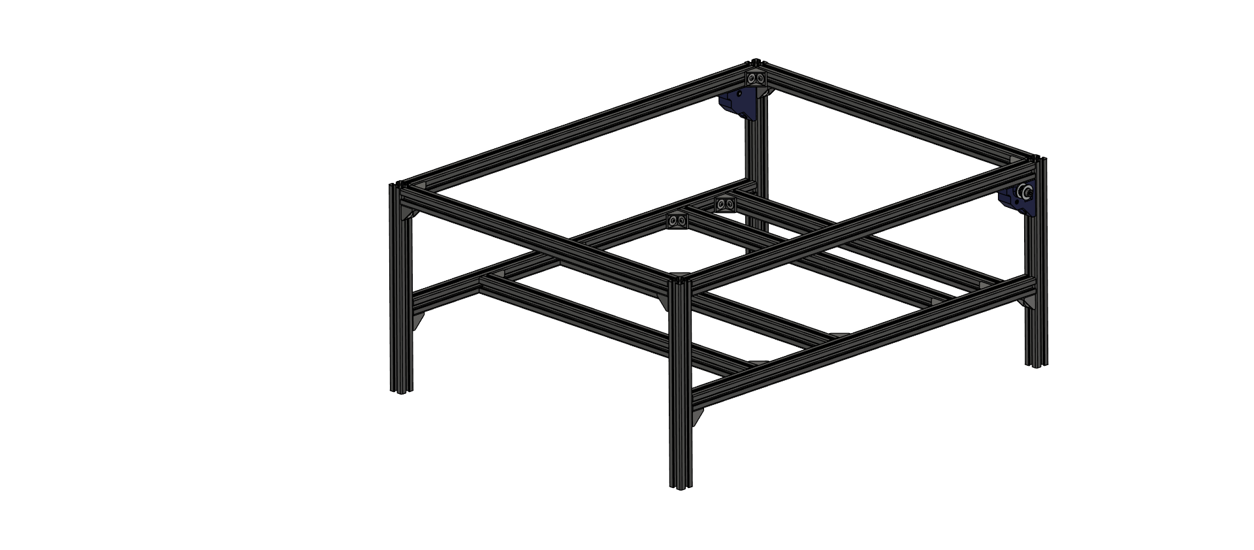
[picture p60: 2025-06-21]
assets/Assembly Manual R01/023 - Legs done.png

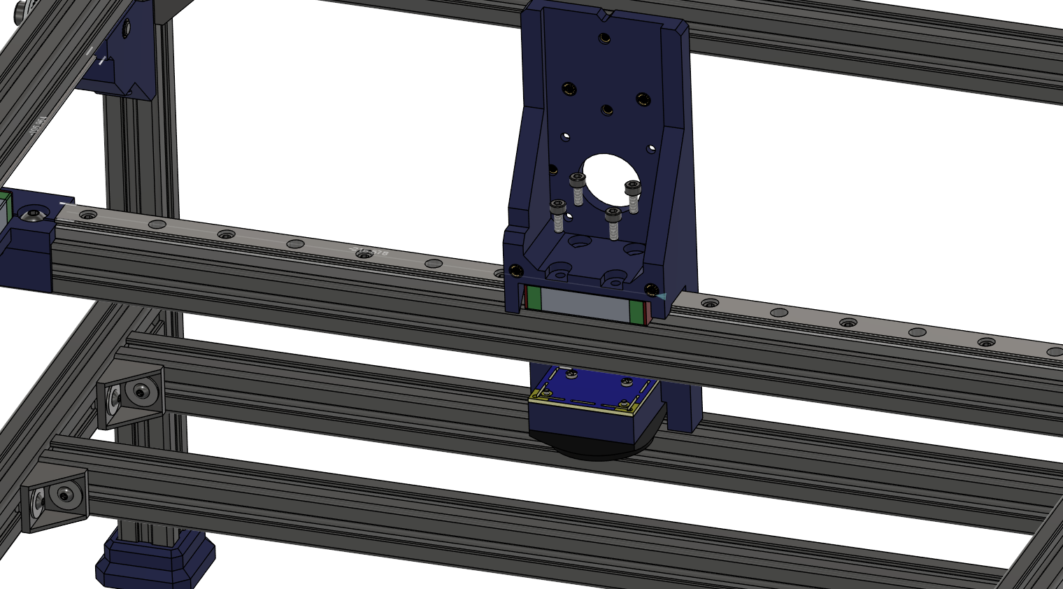
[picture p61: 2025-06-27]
assets/Assembly Manual R01/079 - Head g.png

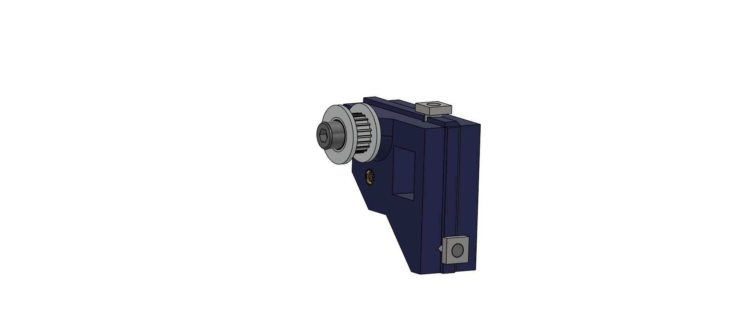
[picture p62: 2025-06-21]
assets/Assembly Manual R01/013 - Corner Idler Y f.png

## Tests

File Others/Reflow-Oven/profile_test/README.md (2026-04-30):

# Reflow Oven Tester UI (profile_test)

Simplified desktop UI to test current oven status and controls, with a layout that is easier to port to an SPI LCD later.

## Features

- Flat UI structure: status row, live plot, control rows, profile point table
- Serial connection to firmware line format (`time_ms,temp_C,top,bottom`)
- CSV playback simulation mode using existing logs
- Profile load/save and point-based editing (stage/time/temp)
- Preheat mode and profile mode
- Manual element commands (A/T/B/X/S/M/P/R)
- Control rule:
	- In `preheat` and `soak`, if measured temperature is above target, target is clamped to current temperature
	- In `cooldown`, warning `OPEN DOOR (cooldown too slow)` is shown when cooling lags target

## Run

```bash
cd Reflow-Oven/profile_test
pip install -r requirements.txt
python oven_tester_ui.py
```

## Defaults

- Profile: `../v01_test/leaded.json`
- Simulation CSV: `../v01_test/reflowTest_001.csv`

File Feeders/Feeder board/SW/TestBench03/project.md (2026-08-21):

Closed-loop wheel-position test bench for the feeder.

Same board and same DRV8833 driver IC as `TestBench02`, plus an AS5600
magnetic rotary encoder on the sprocket shaft so the wheel can be commanded
to an absolute angle (or a tooth step) and the firmware closes the loop
against real position feedback instead of running open-loop.

DRV8833 channel A drives the front (tape-feed) sprocket motor,
closed-loop via the AS5600. DRV8833 channel B drives the rear (peel)
motor, which pulls the cover tape — it has **no position feedback of its
own**, so it's always driven open-loop, fixed on/off (no PWM/variable
speed). Motor B is only ever driven:

- **after** motor A completes a move/feed that turns out to be in the
  real-world **forward** direction (tap-jog, `STEP+`/`T`/`A` commands that
  move forward, or forward continuous feed) — motor B then runs alone for
  exactly as long as that move/feed took. It is **never** driven for A's
  reverse motion, and never runs *while* A is moving (sequential, not
  concurrent — see "PEEL-after-forward, continuous feed, and the manual
  PEEL command" below for why).
- alone, for a fixed duration, on the manual `PEEL` command (GO+
  double-tap or serial `PEEL`).

Sketch files:

- `drv8833_as5600_testbench.ino` (Arduino IDE, identical to `src/main.cpp`)
- `src/main.cpp` (PlatformIO)

## Is 1-tooth / 0.5-tooth indexing doable? Yes.

The wheel has 40 teeth, so:

- 1 tooth = 360° / 40 = **9.0°**
- 0.5 tooth = **4.5°**

The AS5600 is a 12-bit absolute encoder: 4096 counts per revolution, i.e.
360° / 4096 = **0.088° per count**. A half-tooth step (4.5°) is therefore
about **51 encoder counts**, roughly 51x finer than the coarsest increment
you need to resolve. There is plenty of margin to stop well inside a
half-tooth window (firmware defaults to a ±0.30° stop tolerance) even
accounting for encoder noise and mechanical backlash.

## Pin map (STM32F411CC Blackpill)

Control inputs (buttons to GND, `INPUT_PULLUP`):

- GO+ input: `PB12` — forward jog button
- GO- input: `PB13` — reverse jog button

Each button reads three gestures (see "PEEL-after-forward, continuous
feed, and the manual PEEL command" below for full behavior):

- **tap** — jog one tooth
- **hold** past `LONG_PRESS_MS` — continuous feed until released
- **double-tap** (GO+ only) — `PEEL`

There is **no hardware abort/STOP button**. Buttons are only acted on
between moves/feeds (`loop()` polls them; `moveToAngle()` and
`continuousFeed()` block synchronously and do not check Serial input while
running — `continuousFeed()` does poll its own triggering button directly,
to know when to stop). A single move can only end via reaching target, the
stall detector (800ms no motion), the 6s move timeout, or `nFAULT`; a
continuous feed ends via button release, the stall detector, or `nFAULT`
(it has no timeout, since duration is however long the button is held).
The serial `STOP` command still exists but likewise only takes effect when
idle, for the same reason.

DRV8833 logic pins:

- `AIN1` -> `PA8` (PWM, forward duty for the front/tape-feed motor)
- `AIN2` -> `PA9` (PWM, reverse duty for the front/tape-feed motor)
- `BIN1` -> `PA10` (rear/peel motor, fixed on/off — no PWM, see below)
- `BIN2` -> `PB9` (rear/peel motor, fixed on/off — no PWM, see below)
- `nSLEEP` -> `PB14` (set HIGH to enable driver)
- `nFAULT` -> `PB15` (input, active LOW)

DRV8833 power and motor pins (not MCU GPIO):

- `VM` -> motor supply (5V to 10.8V as valid for your motors)
- `GND` -> common ground with Blackpill
- `AOUT1`, `AOUT2` -> front/tape-feed motor terminals
- `BOUT1`, `BOUT2` -> rear/peel motor terminals

AS5600 magnetic encoder (I2C1):

- `VCC` -> 3.3V (Blackpill 3V3 rail — the AS5600 is **not** 5V tolerant on
  most breakout boards, check your module's regulator before using 5V)
- `GND` -> common ground
- `SCL` -> `PB6`
- `SDA` -> `PB7`
- `DIR` -> tie to GND if your breakout exposes it (default rotation sense);
  leave unconnected if the breakout doesn't expose the pin
- `OUT` (analog output) -> not connected, firmware reads I2C only

Most AS5600 breakout modules already carry onboard 4.7kΩ pull-ups on
SDA/SCL. If you're wiring a bare AS5600 chip instead of a breakout, add
2.2kΩ–4.7kΩ pull-ups from SDA and SCL to 3.3V yourself.

### Magnet mounting

- Use a diametrically magnetized magnet (AMS recommends 6mm x 2.5mm or
  similar) centered on the motor/wheel shaft, on the side facing the
  AS5600's top marking.
- Keep the magnet 0.5mm–3mm above the chip package; 1mm–2mm is a good
  starting point. Too far and `MAGNITUDE`/`AGC` readings degrade; too close
  and the sensor saturates.
- The encoder must see one full mechanical turn per one full wheel
  revolution (mount it on the wheel shaft itself, or on any 1:1 shaft
  coupled to it — not through a gear reduction, or the tooth math below no
  longer applies).
- If `STATUS`/move logs show `health=WEAK` (`ML=1`) with a low-ish `AGC`
  and `MAGNITUDE` reading well under what you saw at initial setup, the
  magnet is too far from the chip — move it closer, within the 0.5mm–3mm
  range above. A marginal/weak signal like this is also the most likely
  cause of an intermittent `ERROR: magnet lost during move (MD=0)` abort
  that happens within milliseconds of a normal read (i.e. it isn't a
  sustained loss, just the reading flickering across the detection
  threshold) — fix the gap rather than treating that abort as a software
  bug.

## Command protocol (USB serial, 115200 baud, newline terminated)

- `A<deg>` — move to an absolute wheel angle, e.g. `A90.0`
- `T<index>` — move to an absolute tooth index 0–39, e.g. `T5`
- `STEP+1` / `STEP-1` — move by one whole tooth (±9.0°), relative to the
  current commanded target
- `STEP+0.5` / `STEP-0.5` — move by half a tooth (±4.5°)
- `ZERO` — re-run the zero-point (still-duty) auto-calibration on demand
- `STOP` — brake motors A and B immediately (only takes effect when idle; a
  move or continuous feed in progress cannot be interrupted this way, see
  Pin map above)
- `PEEL` — run the rear/peel motor (B) forward for `PEEL_DURATION_MS`; motor
  A is untouched. Serial equivalent of the GO+ double-tap.
- `STATUS` — print current angle, tooth position, target, magnet health
  (`MD`/`ML`/`MH`, `AGC`, `MAGNITUDE`, plus a one-word `health` verdict:
  `OK`/`WEAK`/`STRONG`/`NONE`), calibrated duty values, I2C error count, and
  whether move tracing is on
- `TRACE ON` / `TRACE OFF` — toggle live per-move progress logging (on by
  default); see "Diagnosing a move" below
- `HELP` / `?` — print the command list

Hardware buttons cover a superset of this: GO+ tap jogs +1 tooth then
peels afterward (timed to match), GO- tap jogs -1 tooth only, either
button held runs continuous feed (GO+ peels after release), GO+
double-tapped runs `PEEL` immediately — all usable without a serial
terminal attached. There is no hardware equivalent of `STOP`.

## PEEL-after-forward, continuous feed, and the manual PEEL command

Motor B (rear/peel) has no encoder, so none of its behavior here is
closed-loop — it's either "run alone for exactly as long as A's last
forward move/feed took" or "run open-loop for a fixed time." Related
tuning knobs, all at the top of `src/main.cpp`:

- `LONG_PRESS_MS` (350) — hold a jog button past this and it's a long-press
  instead of a tap.
- `DOUBLE_TAP_WINDOW_MS` (350) — a second GO+ tap starting within this long
  after the first tap's release counts as a double-tap.
- `PEEL_DURATION_MS` (400) — how long the *manual* `PEEL` command drives
  motor B. This is a timed duration, not a measured tape length (no
  feedback exists to measure it) — tune it to how much cover tape one
  manual peel should pull for your mechanism. It does **not** apply to the
  automatic peel described below, which is timed to the move instead.
- `CONTINUOUS_FEED_DUTY` (defaults to `FAST_DUTY`) — motor A's duty during
  continuous feed. There's no target to creep toward while free-running,
  so this is the only speed used.
- `INVERT_DIRECTION_B` — flip if motor B runs backwards from what's
  expected (independent of `INVERT_DIRECTION`, which is motor A only).

**PEEL-after-forward:** whenever a move (`moveToAngle()` — tap-jog, `STEP`,
`T`, `A`) or a continuous feed turns out to be in the real-world forward
direction, motor B does **not** run concurrently with motor A. Instead,
once A finishes (reaches target, or the button is released for continuous
feed), motor B runs alone at its own fixed full-power duty for exactly as
long as A's move/feed just took, then brakes. Motor B has no speed
feedback of its own, so there was no way to know how far it had actually
travelled if run concurrently with A at A's (variable, creep-then-fast)
duty — running it afterward, timed to A's elapsed duration, is the
approximation used instead. A's reverse motion never triggers this. A
failed/aborted move or feed (stall, timeout, fault, magnet loss) does
**not** trigger it either — only a clean completion does.

**Continuous feed (long-press):** holding either jog button past
`LONG_PRESS_MS` switches from "jog one tooth" to "run continuously at
`CONTINUOUS_FEED_DUTY` until the button is released," ignoring
target/tolerance entirely — it's a manual speed-jog, not a closed-loop
move, so there's no move timeout. The stall detector and `nFAULT` are still
live during a continuous feed, same protection as a normal move. When the
button is released, motor A brakes and `targetAngleDeg` is resynced to the
real measured angle — same reasoning as the target auto-resync described
below, so the next tap/hold starts from where the wheel actually is — and
then, if the feed was forward, PEEL-after-forward runs motor B for the
total hold duration.

**Manual PEEL (GO+ double-tap, or serial `PEEL`):** drives only motor B
forward for the fixed `PEEL_DURATION_MS`, immediately, with no associated
move. Motor A is untouched — the sprocket wheel doesn't move. `nFAULT`
still aborts it early, but there's no other way to interrupt a peel in
progress (same "no hardware abort mid-action" reasoning as moves).

**Gesture detection implementation note:** `classifyPress()` blocks (a
short, bounded busy-wait, same style as the rest of this firmware) to tell
tap/double-tap/hold apart before the caller acts — for a hold, it returns
as soon as `LONG_PRESS_MS` is crossed while the button is *still* held, and
the caller (`continuousFeed()`) then polls that same pin directly in its
own loop to know when to stop. This means a GO+ tap's jog doesn't start
until the double-tap window has elapsed with no second tap — by design, to
disambiguate it from a double-tap; GO- has no double-tap gesture, so its
taps register immediately on release.

## Auto zero-point calibration

"Zero point" here means the boundary duty value sent to the DRV8833 that
still keeps the motor **stationary** — the highest PWM duty below the
point where the motor actually starts turning (breakaway/stiction point).
Firmware finds this automatically instead of relying on a guessed constant:

1. On boot (and again any time you send `ZERO`), the motor is braked and
   the current AS5600 angle is recorded as a baseline.
2. Duty is ramped up in small steps (default: from 15 to 200, in steps of
   5, ~60ms per step) while the encoder is watched. As soon as the angle
   moves more than the noise threshold (0.6°) from baseline, that step's
   duty is recorded as `breakaway`, and the previous step (the last one
   that produced no measurable motion) is recorded as `stillDutyMax` —
   the actual zero point.
3. This is repeated independently for each direction, since H-bridge and
   motor characteristics are rarely perfectly symmetric.
4. The closed-loop mover then uses `breakaway + margin` as its low-speed
   "creep" duty when close to target, guaranteeing it can always actually
   move at the commanded creep speed instead of stalling at too low a duty.
5. Any wheel motion incurred during calibration is undone at the end by a
   corrective move back to the pre-calibration angle, so calibration is
   effectively position-neutral.
6. If the AS5600 doesn't report a detected magnet, or the motor never
   breaks away up to the max calibration duty (disconnected motor, stuck
   mechanism, wiring fault), calibration is skipped/aborted and a safe
   default creep duty is used instead — check `STATUS` and the serial log
   if you see this warning.

Calibration results (`stillDutyMax`, `minMoveDutyFwd`, `minMoveDutyRev`)
are printed after every calibration run and are visible any time via
`STATUS`. They are not persisted across power cycles — recalibration runs
automatically on every boot.

## Closed-loop move behavior

- Error is computed as the shortest signed angular path to target (handles
  wraparound at 0°/360° correctly), so the wheel always takes the shorter
  way round.
- Above 3.0° of error, the motor runs at a fixed fast duty (110 by
  default). Inside 3.0°, it drops to the calibrated creep duty for that
  direction to avoid overshoot.
- The move completes and brakes once the error is within ±0.30° — small
  compared to a half-tooth step (4.5°).
- Stall protection: if the encoder shows no motion for 800ms while a move
  is commanded, the move aborts and brakes (protects against a jammed
  wheel or a disconnected motor).
- Overall move timeout: 6 seconds, after which the move aborts and brakes
  even if still not on target.
- Magnet loss: if the AS5600 stops reporting a detected magnet (`MD` bit
  clears) partway through a move, the move aborts immediately with its own
  distinct error instead of being misread as a generic stall.
- `nFAULT` is polled during a move and aborts it immediately. There is no
  button/Serial abort mid-move (see Pin map above) — the stall detector,
  the move timeout, and `nFAULT` are the only ways an in-progress move ends
  early.
- I2C reads are validated (`Wire.endTransmission`/`requestFrom` return
  checked): a failed AS5600 read is logged (throttled) and falls back to the
  last known-good angle instead of feeding a garbage value into the
  stall/tolerance math. Cumulative failure count is visible via `STATUS`
  (`i2cErrors=`).

Tuning knobs live at the top of `src/main.cpp`: `ANGLE_TOLERANCE_DEG`,
`CREEP_THRESHOLD_DEG`, `FAST_DUTY`, and the `CAL_*` constants for
calibration behavior.

There are two completely different "wrong direction" fixes here, at two
different layers. Flipping the wrong one for a given symptom makes things
*worse*, not better — each one individually breaks a different invariant:

- **`INVERT_DIRECTION`** (default `false`) — the motor/encoder
  self-consistency flag. The whole closed loop's convergence depends on
  "driving forward makes the raw angle reading move toward the target";
  flipping this when that's *not* the actual problem breaks that
  invariant and makes the loop fight itself. Symptom that means you
  actually need this one: a move drives away from target, error keeps
  growing instead of shrinking, and it eventually times out after nearly a
  full revolution.
- **`RAW_ANGLE_INCREASE_IS_REVERSE`** (default `true` on this bench) — a
  pure labeling fact, completely separate from the loop's internal
  self-consistency: "does driving the raw AS5600 angle to increase count
  as this mechanism's real-world forward, or reverse?" Everything that
  needs to translate human intent (which way is `+1 tooth`, which way
  `T<index>` counts, when the automatic PEEL-after-forward triggers, which
  label a log line prints) reads this one fact via `TOOTH_STEP_DEG` /
  `toRealForward()`, instead of each place being flipped independently and
  risking drifting out of sync with each other. Symptom that means you
  need *this* one, not `INVERT_DIRECTION`: moves/jogs complete correctly —
  no fighting, no runaway, no timeout — but the resulting real-world
  direction is backwards from what the button/command implies. Confirmed
  needed on this bench: `STEP-2` (a pure target-angle change, no buttons
  involved) completed cleanly but in the physically-backwards direction —
  exactly this symptom, not `INVERT_DIRECTION`'s.

If you ever need to re-derive which one applies: change nothing about the
motor/encoder wiring, run a `STEP` command, and watch the `[move N]` trace
in the log (see "Diagnosing a move" below). If `err` shrinks steadily to
zero and the move completes normally, the loop is self-consistent — only
`RAW_ANGLE_INCREASE_IS_REVERSE` should ever be touched, regardless of which
real-world direction it ends up moving. If `err` grows instead of shrinking
and the move times out after nearly a full revolution, that's
`INVERT_DIRECTION`.

Motor B / gesture tuning (`INVERT_DIRECTION_B`, `LONG_PRESS_MS`,
`DOUBLE_TAP_WINDOW_MS`, `PEEL_DURATION_MS`, `CONTINUOUS_FEED_DUTY`) is
covered in "PEEL-after-forward, continuous feed, and the manual PEEL
command" above.

### Diagnosing a move

Every commanded move, continuous feed, or `PEEL` is tagged with a sequence
number, e.g. `[move 12]`, so its lines can be told apart from the 3-second
`STATUS` heartbeat and from each other in the log. Continuous feed reuses
the same `[move N]` start/trace/abort shape as a normal move (just without
a `target`/`err`, since it has none); `PEEL` only logs a start and an
end/abort line, since it's a plain timed drive with no angle to trace:

- `[move N] start=... target=... err=...` — printed once when the move
  begins.
- `[move N] t=...ms angle=... err=... duty=... dir=... sinceMotion=...ms` —
  printed roughly every 150ms while the move is in progress (`TRACE ON`,
  the default; disable with `TRACE OFF` if it's too noisy). `dir=` is the
  real-world direction (via `toRealForward()`), not the raw motor-pin
  sense, so it matches what you'd actually see the wheel do.
- On any abort (stall, timeout, fault, or magnet loss), a one-line
  reason is followed by a detail line with `start`/`target`/`current`/`err`,
  `elapsed`/`sinceMotion`, the `duty`/`dir` that was being driven, and a
  full magnet health line — enough to tell a real mechanical jam (angle
  genuinely flat, duty at `FAST_DUTY`) apart from a sensor problem (`health`
  not `OK`, or repeated `WARN: AS5600 I2C read failed`) or a stale-target
  problem (large `err` on what should have been a small jog).
- On a clean completion that turned out to be real-world-forward, two more
  lines follow under the *same* `[move N]` tag: `PEEL: running rear motor
  (B) for ...ms (matches this move's duration)` and `PEEL complete` — this
  is the automatic PEEL-after-forward described above, not a new move.

**Motor spinning with no move in progress:** `moveToAngle()` runs
synchronously, so `loop()`'s 3-second `STATUS` heartbeat can only print
between moves, never during one. If you see plain `STATUS`-formatted lines
(no `[move N]` tag) showing the angle changing steadily across heartbeats,
the motor is being driven by something other than the closed-loop logic —
most likely a PWM output that didn't actually turn off. `analogWrite()` on
`PA8`/`PA9` puts those pins into hardware timer mode; a bare `digitalWrite()`
afterward doesn't reliably tear that back down on this core, so a "braked"
pin can keep outputting its last PWM duty. `brakeMotorA()` now forces
`pinMode(..., OUTPUT)` before the brake `digitalWrite`s to guarantee a full
GPIO re-init out of timer/alternate-function mode. As a backstop, the
heartbeat itself now also compares angle across the 3-second interval and
prints `WARN: wheel moved ... deg between heartbeats with no move in
progress` if it ever sees unexplained motion again, regardless of cause.

**Target auto-resync:** if a move aborts before reaching its target,
`targetAngleDeg` previously stayed at the unreached value. Since `GO`/`STEP`
add onto `targetAngleDeg` rather than the wheel's actual position, repeated
failures used to compound silently — each new jog aimed further past a
position the wheel never actually reached, until a "+1 tooth" jog ended up
commanding a move most of the way around the wheel. Firmware now resyncs
`targetAngleDeg` to the real measured angle whenever a commanded move fails,
and logs it (`NOTE: resyncing target to actual angle ...`) so the drift is
visible instead of silent.

### USB "device not recognized" note

Same as `TestBench02`: on STM32F411, USB FS data pins are `PA11` (D-) and
`PA12` (D+). This firmware does not drive either pin, so no special
workaround is needed here, but avoid reassigning motor or encoder pins onto
`PA11`/`PA12` if you customize the pin map.

## PlatformIO + DFU

This folder includes a PlatformIO project:

- `platformio.ini`
- `src/main.cpp`

Default environment:

- `blackpill_f411cc_dfu` (board `genericSTM32F411CC`)

Fallback environment (if your PlatformIO package does not include F411CC
board ID):

- `blackpill_f411ce_dfu`

### Build

From this folder:

```bash
pio run -e blackpill_f411cc_dfu
```

### Upload with DFU

1. Connect Blackpill by USB.
2. Put MCU in system bootloader mode (BOOT0 high, then reset).
3. Upload:

```bash
pio run -e blackpill_f411cc_dfu -t upload
```

4. Return BOOT0 low and reset to run firmware normally.

If `genericSTM32F411CC` is not recognized, use:

```bash
pio run -e blackpill_f411ce_dfu -t upload
```

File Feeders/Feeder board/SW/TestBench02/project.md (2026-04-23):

Simple test project for the feeders

2x DRV8833 driving two miniatrue DC motors
One feeds tape, one pulls cover tape

Optocoupler as position encoder via holes in the main feed wheel
Based on a STM32F411CC Blackpill

## Test bench: GO/STOP with hard brake

This test bench uses two digital inputs:

- GO input: runs motor A and motor B forward at low speed (sync)
- STOP input: hard-brakes motor A and motor B

Sketch file:

- `drv8833_testbench.ino`

### Pin map (STM32F411CC Blackpill)

Control inputs:

- GO input: `PB12` (button to GND, `INPUT_PULLUP`)
- STOP input: `PB13` (button to GND, `INPUT_PULLUP`)

DRV8833 logic pins:

- `AIN1` -> `PA8` (PWM)
- `AIN2` -> `PA9`
- `BIN1` -> `PA10` (motor B drive)
- `BIN2` -> `PB9` (motor B drive)
- `nSLEEP` -> `PB14` (set HIGH to enable driver)
- `nFAULT` -> `PB15` (input, active LOW)

DRV8833 power and motor pins (not MCU GPIO):

- `VM` -> motor supply (example: 5V to 10.8V as valid for your setup)
- `GND` -> common ground with Blackpill
- `AOUT1`, `AOUT2` -> Motor A terminals
- `BOUT1`, `BOUT2` -> Motor B terminals

### Behavior

- GO pressed: motor A and B run with a short startup kick (`START_KICK_DUTY = 110` for 300 ms), then low duty (`LOW_SPEED_DUTY = 40`, about 16% PWM)
- STOP pressed: hard brake on both channels (`AIN1 = HIGH`, `AIN2 = HIGH`, `BIN1 = HIGH`, `BIN2 = HIGH`)
- Fault asserted (`nFAULT = LOW`): immediate hard brake on both motors

Logic mapping knobs in firmware:

- `BUTTONS_ACTIVE_LOW = true` for pull-up + button-to-GND wiring
- `SWAP_GO_STOP_ACTIONS = true` if physical GO/STOP controls are wired opposite to labels

If your motor does not move at duty 40, increase gradually (for example 50, 60, 70) until motion is stable.

### USB "device not recognized" note

On STM32F411, USB FS data pins are `PA11` (D-) and `PA12` (D+). If your firmware drives `PA11` as GPIO/PWM, USB enumeration can fail and Windows may report an unrecognized USB device.

This project now keeps only `BIN2` off `PA11` (moved to `PB9`) to avoid that conflict when CDC serial is enabled while preserving the rest of the original motor wiring.

## PlatformIO + DFU

This folder now includes a PlatformIO project:

- `platformio.ini`
- `src/main.cpp`

Default environment:

- `blackpill_f411cc_dfu` (board `genericSTM32F411CC`)

Fallback environment (if your PlatformIO package does not include F411CC board ID):

- `blackpill_f411ce_dfu`

### Build

From this folder:

```bash
pio run -e blackpill_f411cc_dfu
```

### Upload with DFU

1. Connect Blackpill by USB.
2. Put MCU in system bootloader mode (BOOT0 high, then reset).
3. Upload:

```bash
pio run -e blackpill_f411cc_dfu -t upload
```

4. Return BOOT0 low and reset to run firmware normally.

If `genericSTM32F411CC` is not recognized, use:

```bash
pio run -e blackpill_f411ce_dfu -t upload
```

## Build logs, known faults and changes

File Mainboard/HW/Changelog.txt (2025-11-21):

[NP] = Not produced
[NW] = Not working after testing

[0.3a]
- Switched to dual USB HUB chips for better bandwidth availability
- Switched to custom SMPS design on-board instead of NID modules
- Added test points on USB for bypass
- Added LEDs on 5V and 12V power
- Schematic now uses logic blocks for MCU and other components
- Added fuse from IN to buck converters (motors still get 24V directly!)
- CHANGED DIMENSIONS!!!

[0.2a] [NP]
- Changed USB hub chip to VSON variant for better availability
- Fixed USB hub connections, added capacitors to SSTX and resistor to R1 pin
- Added filtering RC to GND on USB connectors shells
- Rerouted USBSS signals for newly added capacitors
- Fixed bootstrap capacitor being placed across the wrong pins causing 3v3 to never come up
- Changed fuse holders for Issues in soldering (hard to solder SMD in limited space, THT should be better)
- Added power LED on 3V3 rail (should not light up if 5V off, which means 12V is off, which means board is off?)
- Added Test Points on most crucial signals

[0.1c] [NP]
- Fixed capacitor C50 footprint being not visible

[0.1b] [NW]
- Fixed some layout Issues
- Added 2D matrix for traceability

[0.1a] [NP]
- Initial revision of board

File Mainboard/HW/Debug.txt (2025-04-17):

[0.1b]

3V3 RAIL NOT WORKING [FIXED]
- Replaced R_high on the 3v3 buck to ensure it was 100k, still not turning to 3v3
- Tried to feed 3V3 from the rail to check FB voltage, spot on at 600mV (precisely what the SY chip needs)
- Tried increasing output capacitance to compensate for suboptimal performance of the 2x22uF caps but not resolving
- Fixed placement of BS capacitor C12, now across pins 5-6. Fixed the issue.

USB HUB NOT DETECTED [FIXED]
- Placed the correct 19k2 resistor on pin 1 to GND to fix the issue. Still not enumerating on windows

USB HUB NOT ENUMERATING [FIXED]
- Cut traces of SSTX to the hub and placed 100nF capacitors in series (LCSC code: C1525 / OrionID: 52), fixed the issue, hub working.

USB NOT WORKING ON STM32
- Adjusted settings for flash to make sure PLL is working at intended frequency, fixed the issue, USB COM port now working properly.

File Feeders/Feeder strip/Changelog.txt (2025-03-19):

[NP] = Not produced
[NW] = Not working after testing

[0.1b]
- Removed 2D matrix for tracking. Not needed on strip.
- Added silkscreen for TERM -> termination resistor switch.

[0.1a] [NP]
- Initial revision of board

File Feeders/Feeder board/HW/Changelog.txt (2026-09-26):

[NP] = Not produced
[NW] = Not working after testing

[0.2]
- New design for HW revision 3
- Switched to AS5600 magnetic encoder for sprocket position after bench test validated as viable
- Reduced BOM even further
- Reduced footprint to reduce cost
- Switched to 1 LED and 2 buttons

[0.2a] [NP]
- Total redesign according to HW revision 2
- Improved pricing by using resettable fuse and fewer components
- Switched to powerPad variant of the motor driver for better availability
- Switched to ATMega328PB as MCU
- Lowered part count as much as possible to aid in cost reduction
- Switched to double optical photointerrupters to get precise feedback (placed so they should allow 2mm pitch component feeding)

[0.1b] [NP]
- Changed components placement to better suit assembly
- Improved labeling and silkscreens
- Added verification hole to check advancement
- Moved LEDs to be aligned in the LED sub board
- Removed holes for motors, thicker frame and thinner PCB will be used. Motor held by PCB and frame.

[0.1a] [NP]
- Initial revision of board

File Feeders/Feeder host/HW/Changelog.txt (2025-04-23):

[NP] = Not produced
[NW] = Not working after testing

[0.2a]
- Redesign for smaller footprint and added functionality
- Switched to STM32F072 for added serials
- Added 3rd line of RS485 bus to be used as programmer
- Embedded a programming strip and switch, with Relay control
- Added i2c OLED screen and encoder for programming
- Switched to the same connectors used for the mainboard
- Activity, programming, power and fault LED on board
- RX and TX indicator LEDs per bus

[0.1d] [NP]
- Added fiducials for future PnP compatibility
- Changed LED resistors to 2k_0805 to improve lifespan
- Added diode to FAULT LED to keep active on MCU failure

[0.1c] [NP]
- Added TP in various crucial points to aid debug.

[0.1b] [NP]
- Changed fills to remove spokes and use direct connection, more contact area = better?
- Moved some components' silkscreen markings for better readability

[0.1a] [NP]
- Initial revision of board

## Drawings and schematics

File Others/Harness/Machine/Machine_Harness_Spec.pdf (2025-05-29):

## Description

## Harness from PCB to devices and toolboard

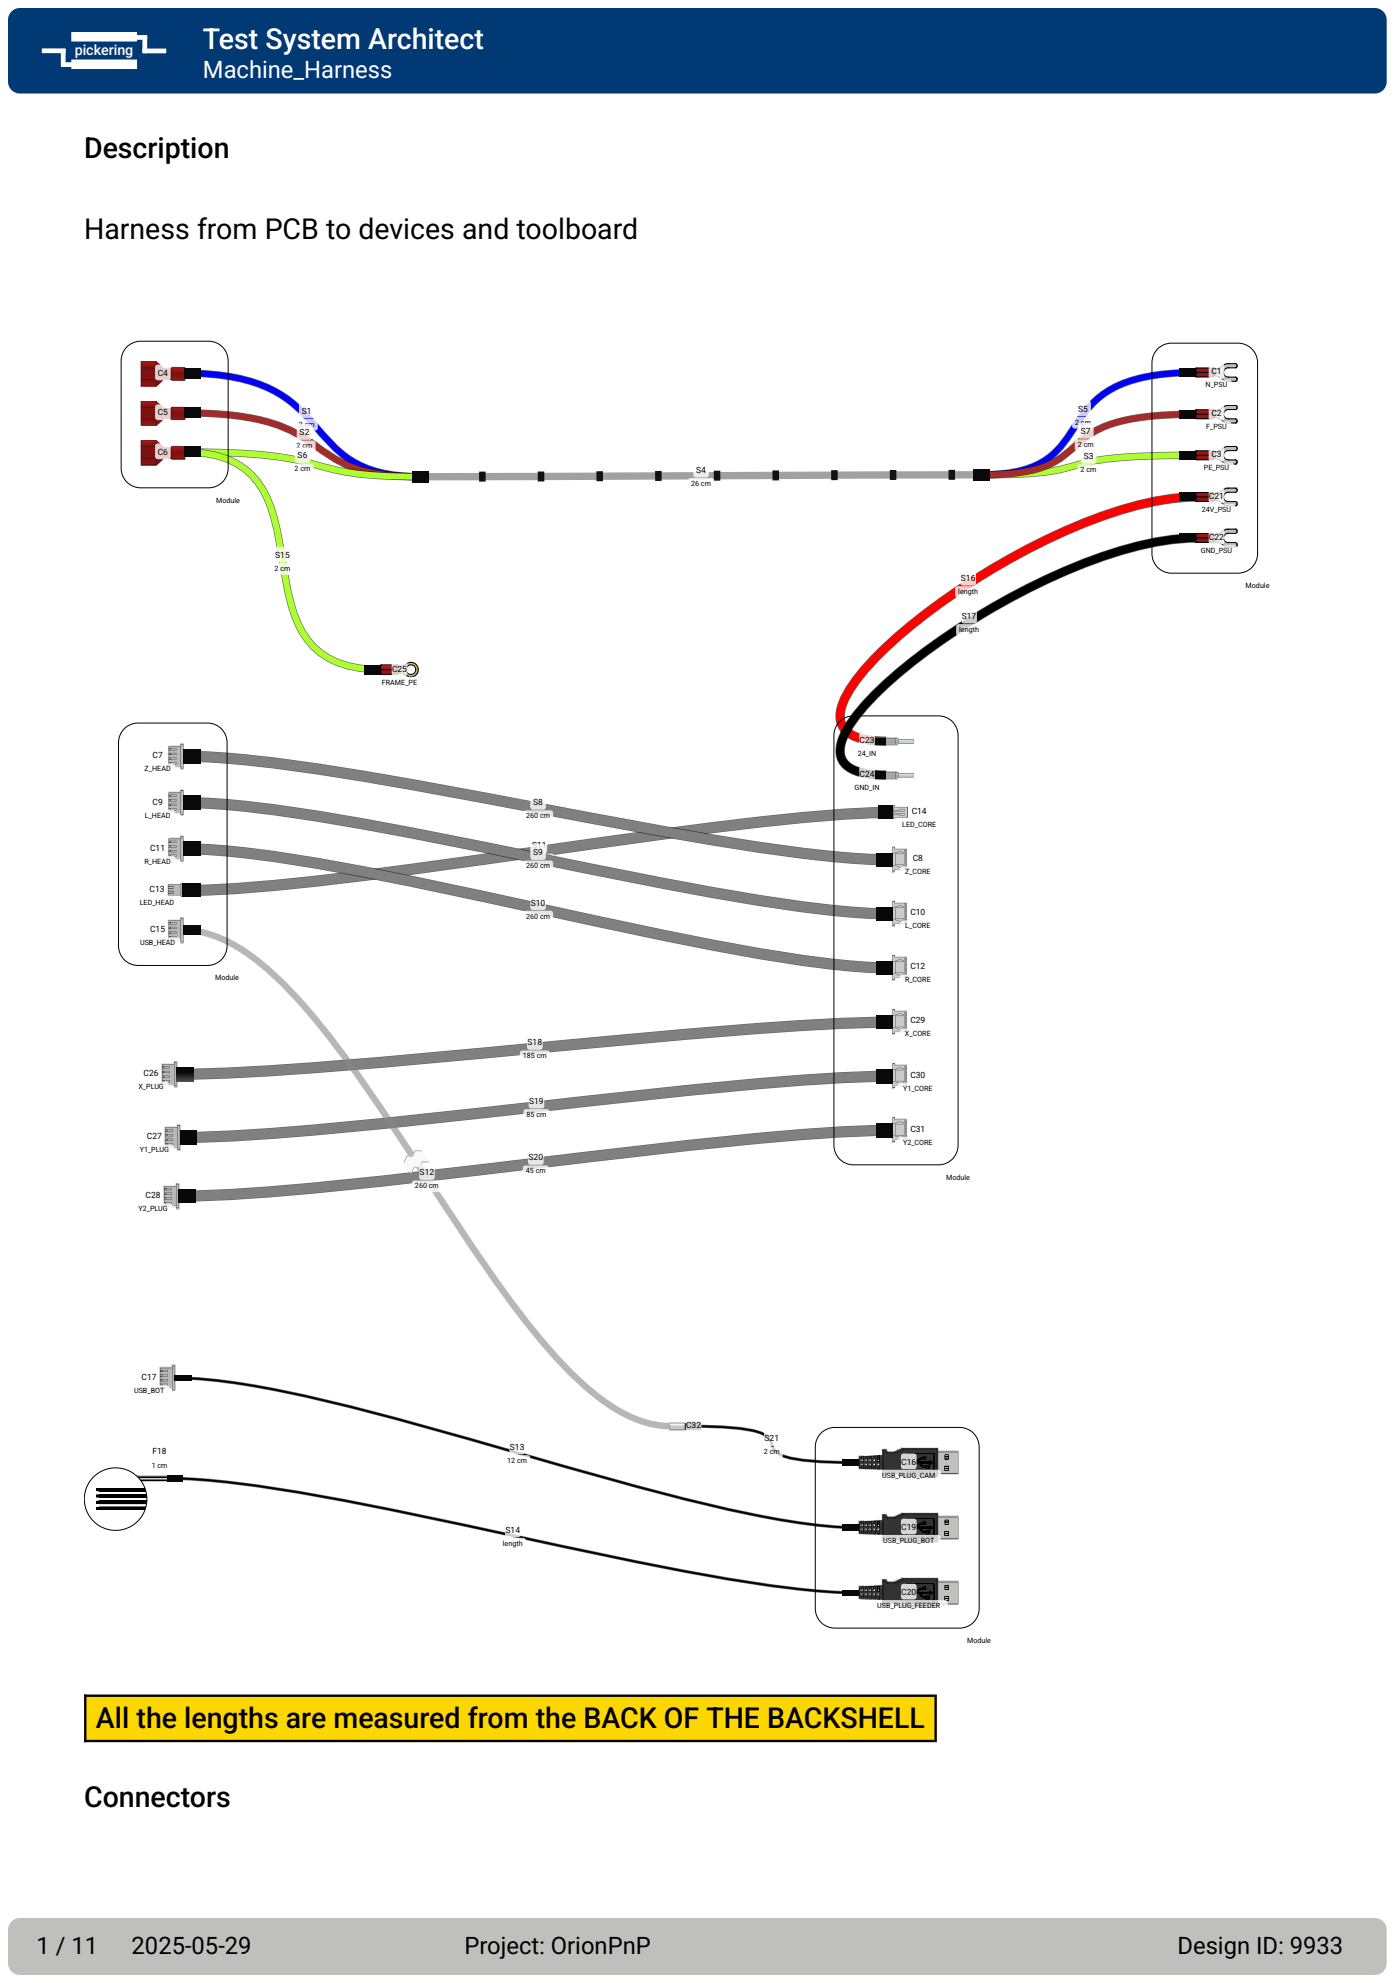
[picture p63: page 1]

All the lengths are measured from the BACK OF THE BACKSHELL

Letter | Name | Manufacturer PN | Custom Name | Number of Pins | Gender
C1 | M5 Crimp Fork Terminal Red 16-22AWG | 534-250 | N_PSU
C3 | M5 Crimp Fork Terminal Red 16-22AWG | 534-250 | PE_PSU
C2 | M5 Crimp Fork Terminal Red 16-22AWG | 534-250 | F_PSU
C4 | Crimp 6.3x0.8mm Faston M 22-16AWG Insulated Red | BM 80180
C5 | Crimp 6.3x0.8mm Faston M 22-16AWG Insulated Red | BM 80180
C6 | Crimp 6.3x0.8mm Faston M 22-16AWG Insulated Red | BM 80180
C7 | 4 Pin XH F Shell (JST) | XHP-4 | Z_HEAD | 4 | Female
C8 | 4 Pin XH F Shell (JST) | XHP-4 | Z_CORE | 4 | Female
C9 | 4 Pin XH F Shell (JST) | XHP-4 | L_HEAD | 4 | Female
C10 | 4 Pin XH F Shell (JST) | XHP-4 | L_CORE | 4 | Female
C11 | 4 Pin XH F Shell (JST) | XHP-4 | R_HEAD | 4 | Female
C12 | 4 Pin XH F Shell (JST) | XHP-4 | R_CORE | 4 | Female
C14 | 2 Pin XH F Shell (JST) | XHP-2 | LED_CORE | 2 | Female
C13 | 2 Pin XH F Shell (JST) | XHP-2 | LED_HEAD | 2 | Female
C15 | 4 Pin XH F Shell (JST) | XHP-4 | USB_HEAD | 4 | Female
C16 | 4 Pin USB-A 2.0 M (CNC Tech) | 1002-001-BL-KIT | USB_PLUG_CAM | 4 | Male
C17 | 4 Pin XH F Shell (JST) | XHP-4 | USB_BOT | 4 | Female
C19 | 4 Pin USB-A 2.0 M (CNC Tech) | 1002-001-BL-KIT | USB_PLUG_BOT | 4 | Male
C20 | 4 Pin USB-A 2.0 M (CNC Tech) | 1002-001-BL-KIT USB_PLUG_FEEDER | 4 | Male
C21 | M5 Crimp Fork Terminal Red 16-22AWG | 534-250 | 24V_PSU
C22 | M5 Crimp Fork Terminal Red 16-22AWG | 534-250 | GND_PSU
C23 | Crimp Butt Splice Terminal Blue 10-12AWG to 14-16AWG (TE Connectivity) | 327637 | 24_IN
C24 | Crimp Butt Splice Terminal Blue 10-12AWG to 14-16AWG (TE Connectivity) | 327637 | GND_IN
C25 | M5 Crimp Ring Terminal Red 15-23AWG | 130014 | FRAME_PE
C26 | 4 Pin XH F Shell (JST) | XHP-4 | X_PLUG | 4 | Female
C27 | 4 Pin XH F Shell (JST) | XHP-4 | Y1_PLUG | 4 | Female
C28 | 4 Pin XH F Shell (JST) | XHP-4 | Y2_PLUG | 4 | Female
C29 | 4 Pin XH F Shell (JST) | XHP-4 | X_CORE | 4 | Female
C30 | 4 Pin XH F Shell (JST) | XHP-4 | Y1_CORE | 4 | Female
C31 | 4 Pin XH F Shell (JST) | XHP-4 | Y2_CORE | 4 | Female
C32 | Crimp Butt Splice Uninsulated 22-16AWG | 809-2369

## Pins

Letter | Name | Manufacturer PN Gender
C7 | XH F Crimp Pin 22-28AWG (JST) | SXH-001T-P0.6 | Female
C8 | XH F Crimp Pin 22-28AWG (JST) | SXH-001T-P0.6 | Female
C9 | XH F Crimp Pin 22-28AWG (JST) | SXH-001T-P0.6 | Female
C10 | XH F Crimp Pin 22-28AWG (JST) | SXH-001T-P0.6 | Female
C11 | XH F Crimp Pin 22-28AWG (JST) | SXH-001T-P0.6 | Female
C12 | XH F Crimp Pin 22-28AWG (JST) | SXH-001T-P0.6 | Female
C14 | XH F Crimp Pin 22-28AWG (JST) | SXH-001T-P0.6 | Female
C13 | XH F Crimp Pin 22-28AWG (JST) | SXH-001T-P0.6 | Female
C15 | XH F Crimp Pin 22-28AWG (JST) | SXH-001T-P0.6 | Female
C17 | XH F Crimp Pin 22-28AWG (JST) | SXH-001T-P0.6 | Female
C26 | XH F Crimp Pin 22-28AWG (JST) | SXH-001T-P0.6 | Female
C27 | XH F Crimp Pin 22-28AWG (JST) | SXH-001T-P0.6 | Female
2 / 11 | 2025-05-29 | Project: OrionPnP | Design ID: 9933

Letter | Name | Manufacturer PN Gender
C28 | | XH F Crimp Pin 22-28AWG (JST) | | | SXH-001T-P0.6 | Female
C29 | | XH F Crimp Pin 22-28AWG (JST) | | | SXH-001T-P0.6 | Female
C30 | | XH F Crimp Pin 22-28AWG (JST) | | | SXH-001T-P0.6 | Female
C31 | | XH F Crimp Pin 22-28AWG (JST) | | | SXH-001T-P0.6 | Female
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

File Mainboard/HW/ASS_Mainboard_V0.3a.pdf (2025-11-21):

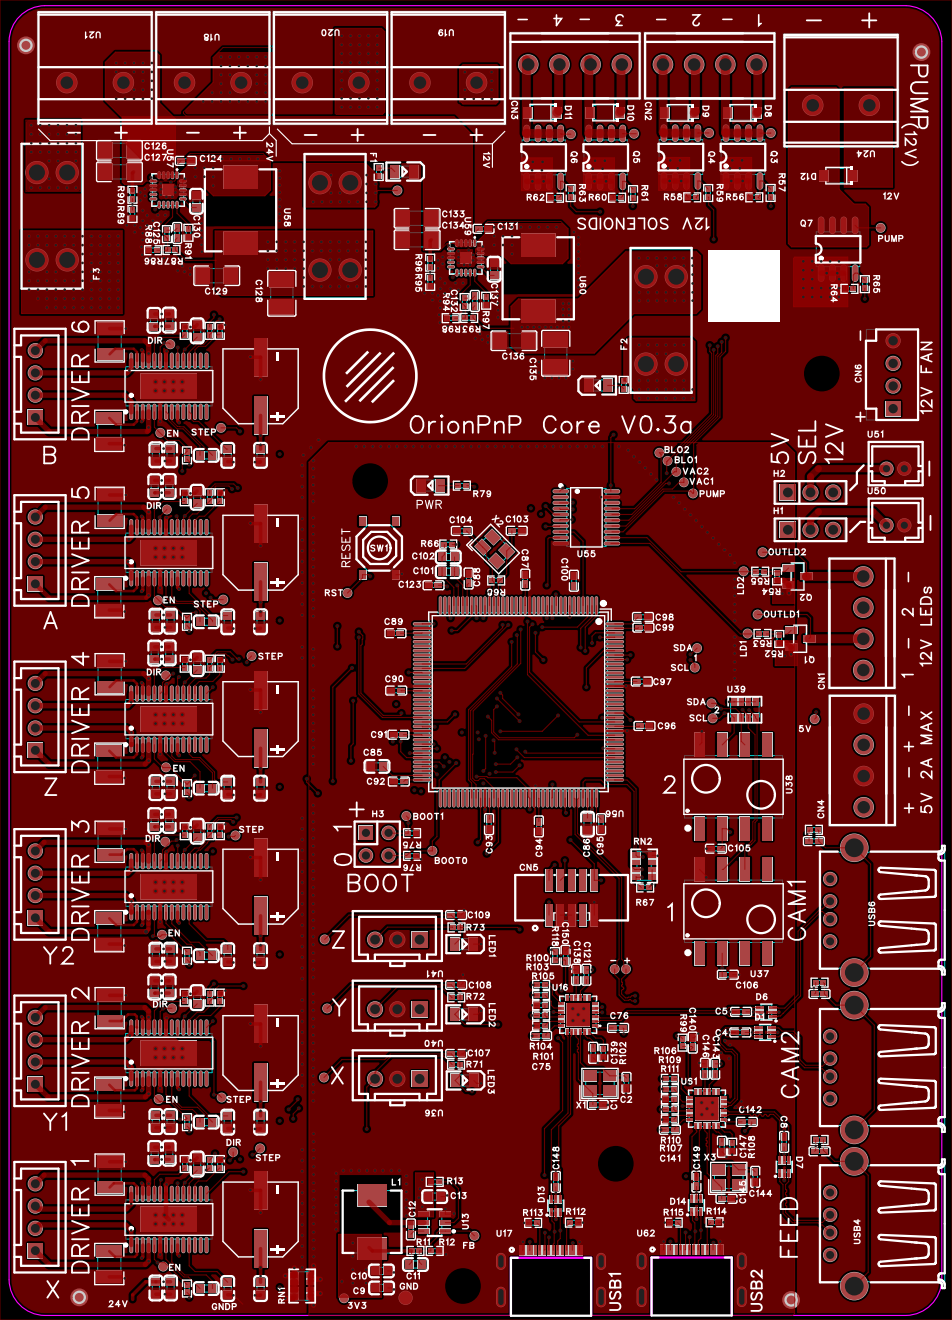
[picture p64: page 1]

DRIVER 1 DRIVER 2 DRIVER 3 DRIVER 4 DRIVER 5 DRIVER 6

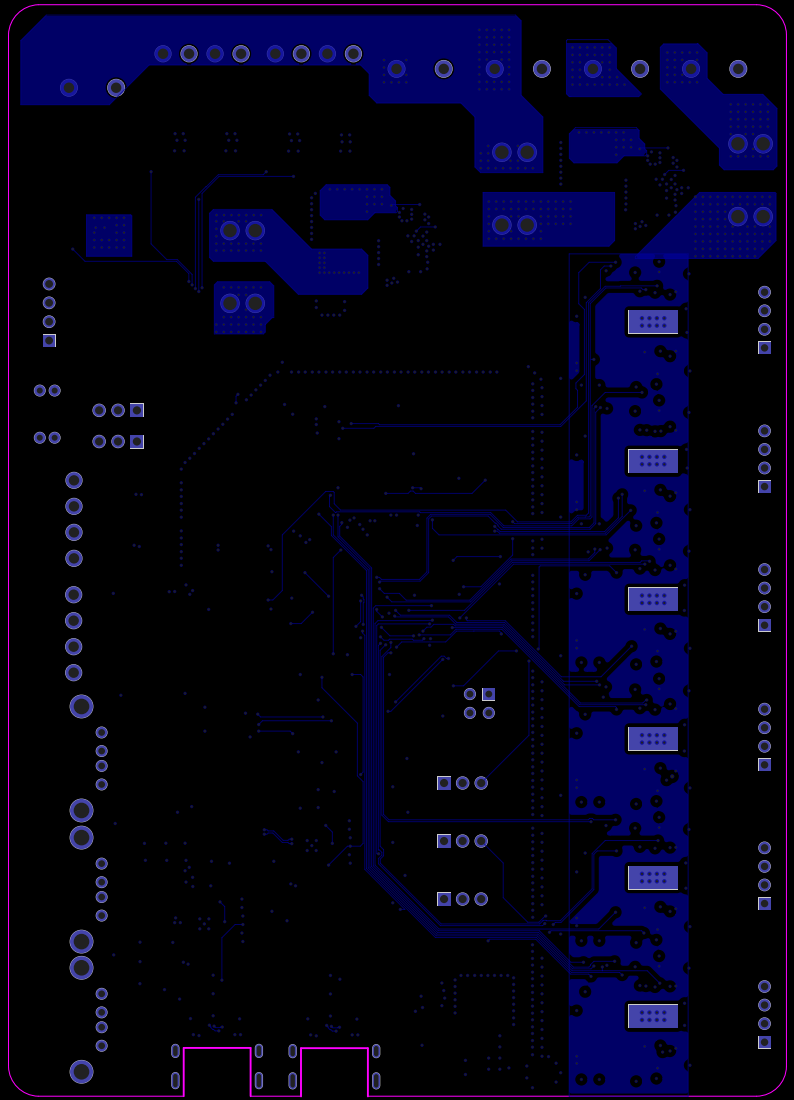
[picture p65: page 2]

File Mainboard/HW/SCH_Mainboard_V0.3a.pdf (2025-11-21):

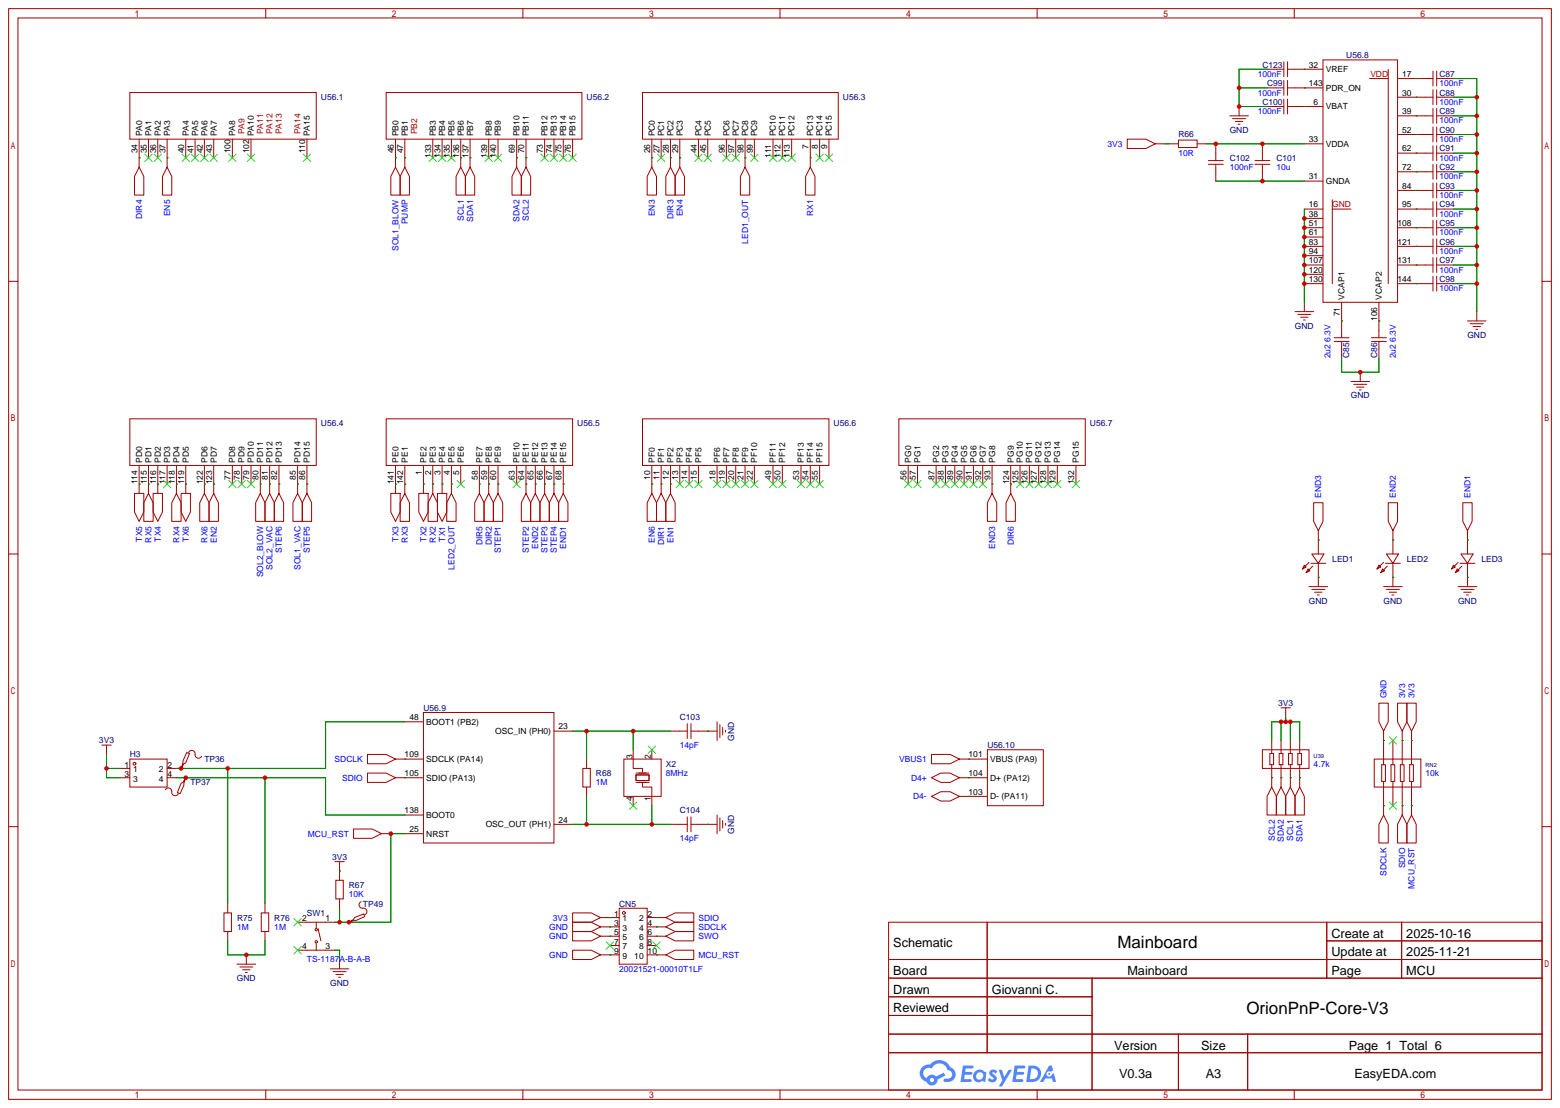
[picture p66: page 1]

Schematic | Mainboard | Create at | 2025-10-16

Update at | 2025-11-21

Board | Mainboard | Page | MCU
Drawn | Giovanni C. | OrionPnP-Core-V3
Reviewed

Version | Size | Page 1 Total 6
V0.3a | A3 | EasyEDA.com

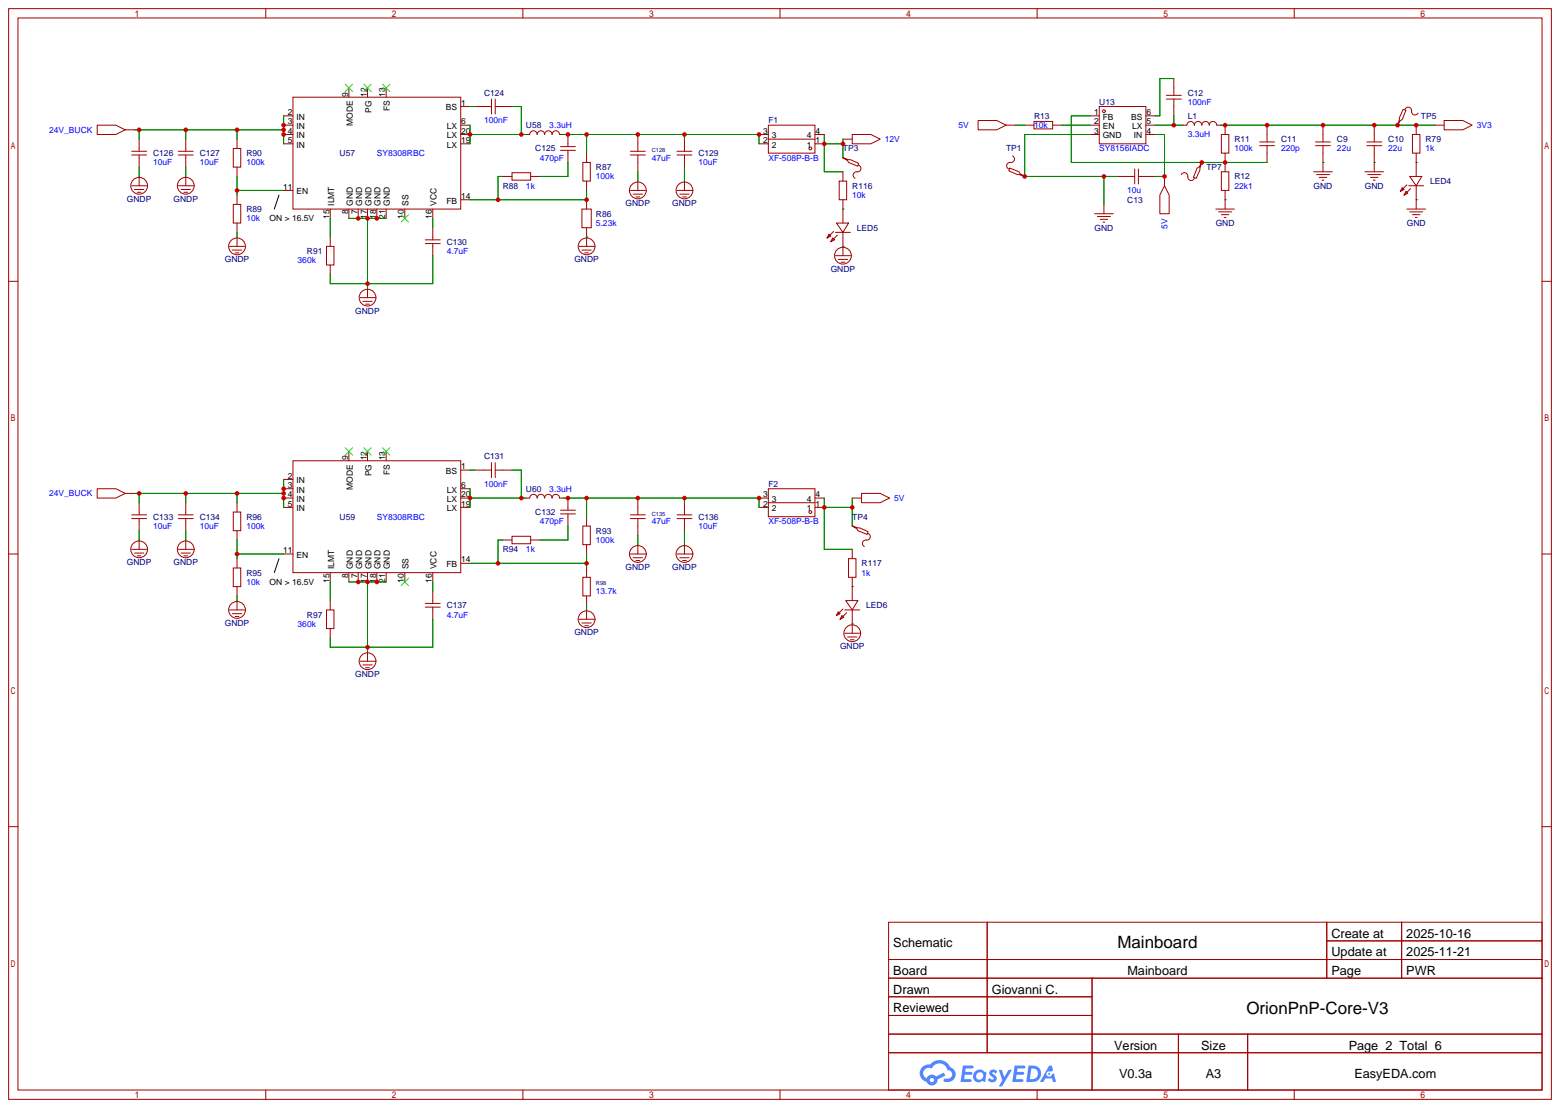
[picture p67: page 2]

Schematic | Mainboard | Create at | 2025-10-16

Update at | 2025-11-21

Board | Mainboard | Page | PWR
Drawn | Giovanni C. | OrionPnP-Core-V3
Reviewed

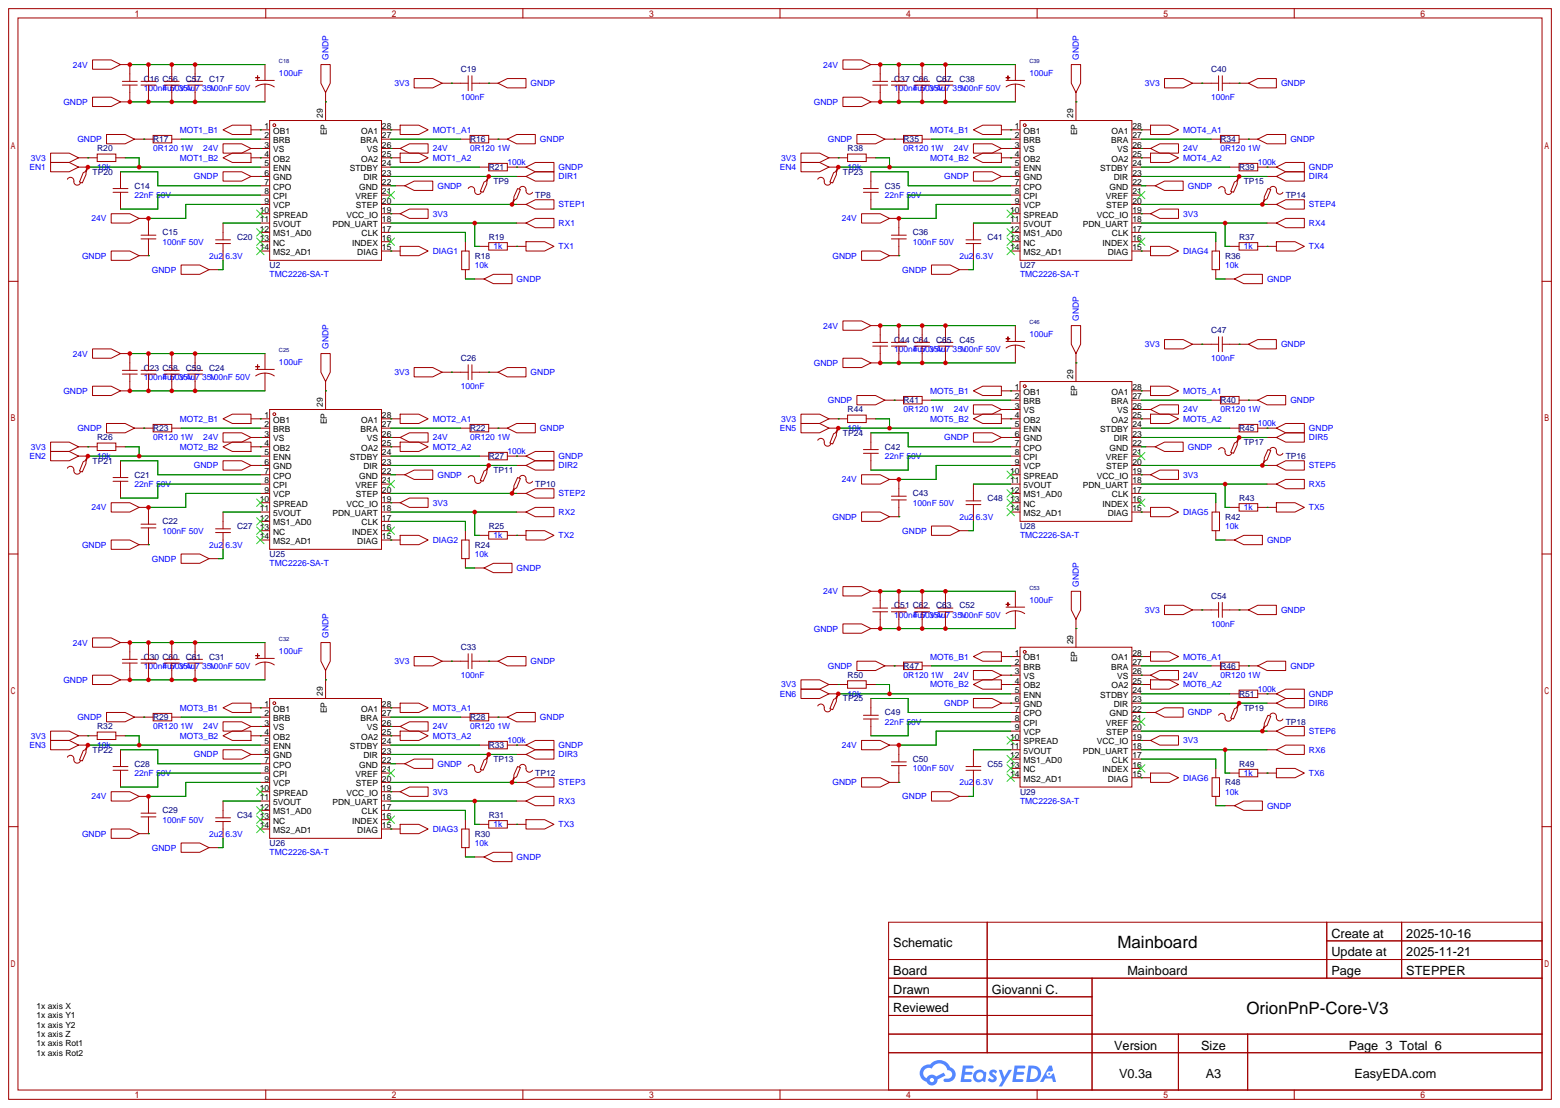
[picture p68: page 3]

Schematic | Mainboard | Create at | 2025-10-16

Update at | 2025-11-21

Board | Mainboard | Page | STEPPER
Drawn | Giovanni C. | OrionPnP-Core-V3
Reviewed

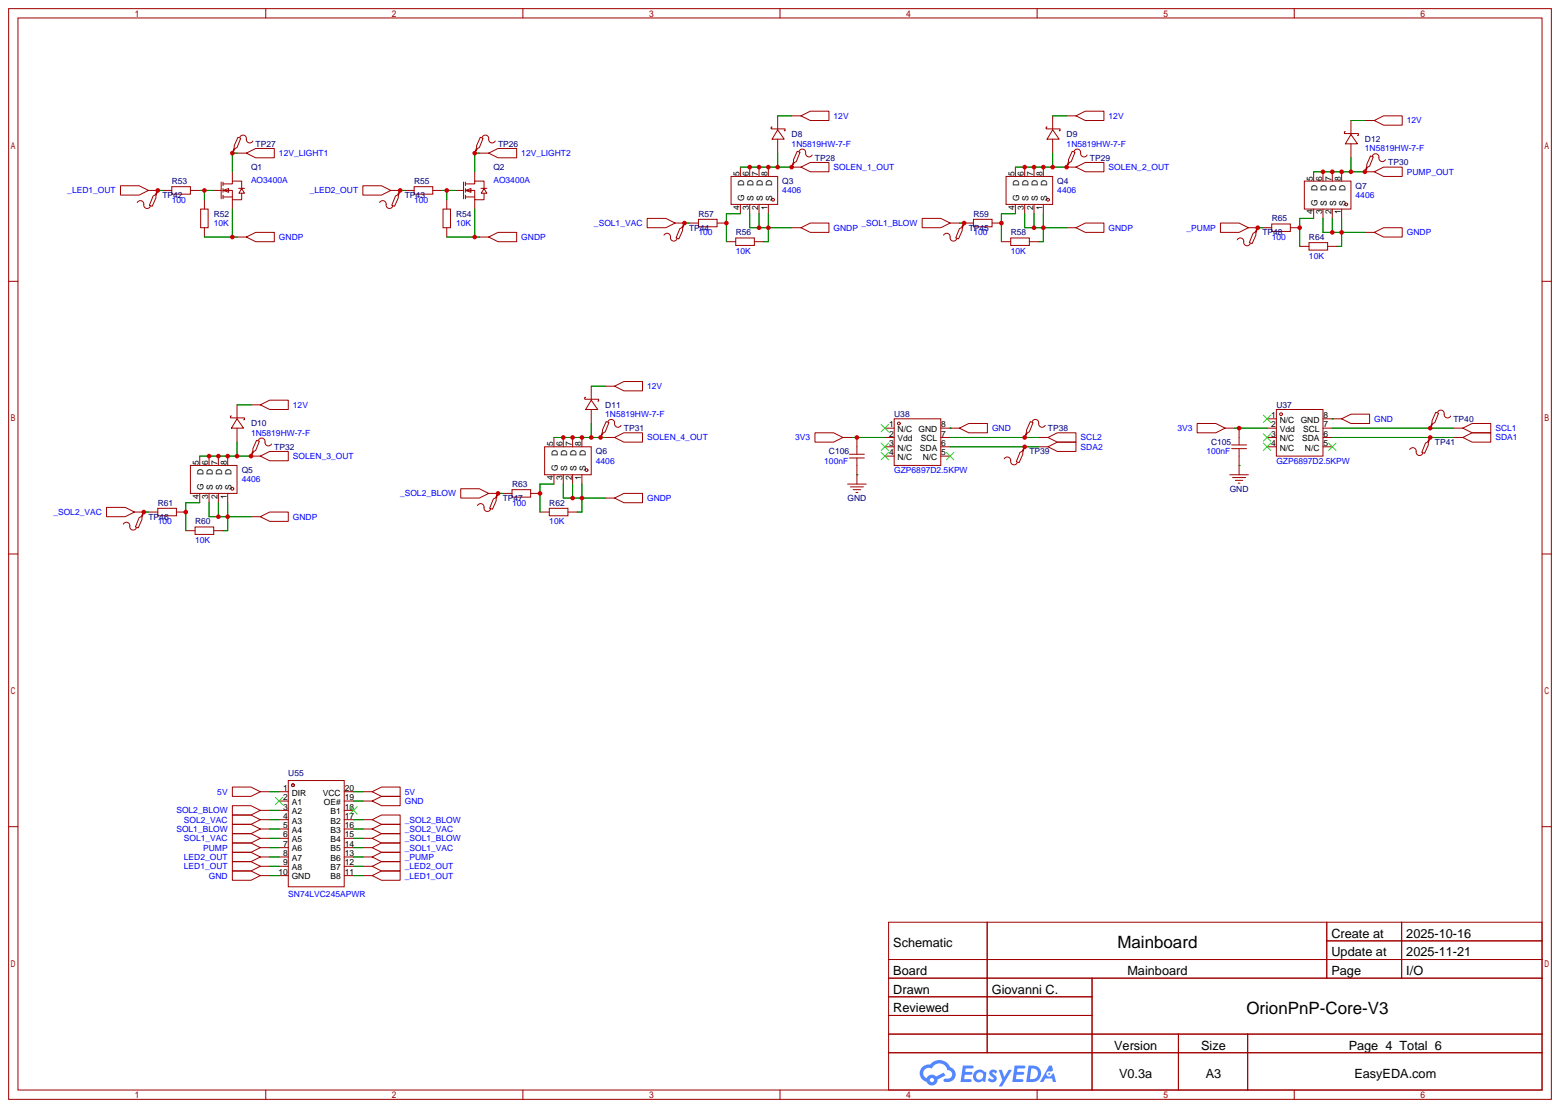
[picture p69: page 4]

Schematic | Mainboard | Create at | 2025-10-16

Update at | 2025-11-21

Board | Mainboard | Page | I/O
Drawn | Giovanni C. | OrionPnP-Core-V3
Reviewed

# 5V_USR 5V5V_USR

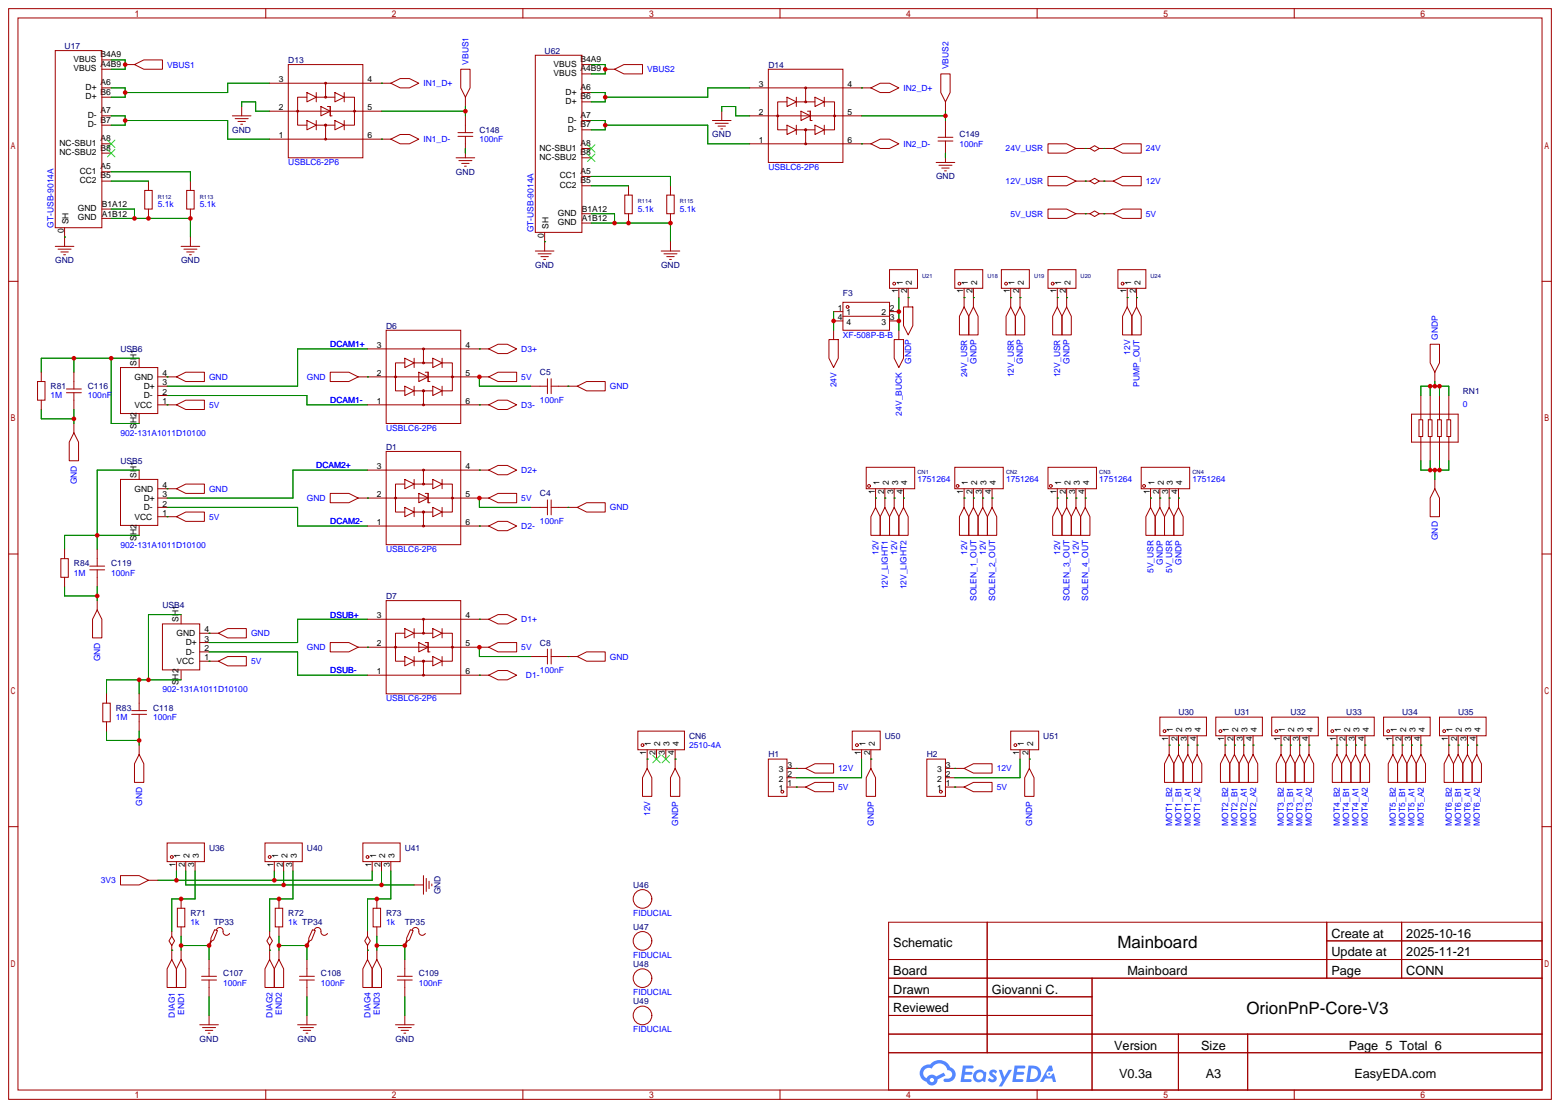
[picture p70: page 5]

Schematic | Mainboard | Create at | 2025-10-16

Update at | 2025-11-21

Board | Mainboard | Page | CONN
Drawn | Giovanni C. | OrionPnP-Core-V3
Reviewed

# GND R¹¹⁸ 10k 100nF C¹⁵⁰ GND R⁹⁹ 10k 100nF C¹⁴⁰

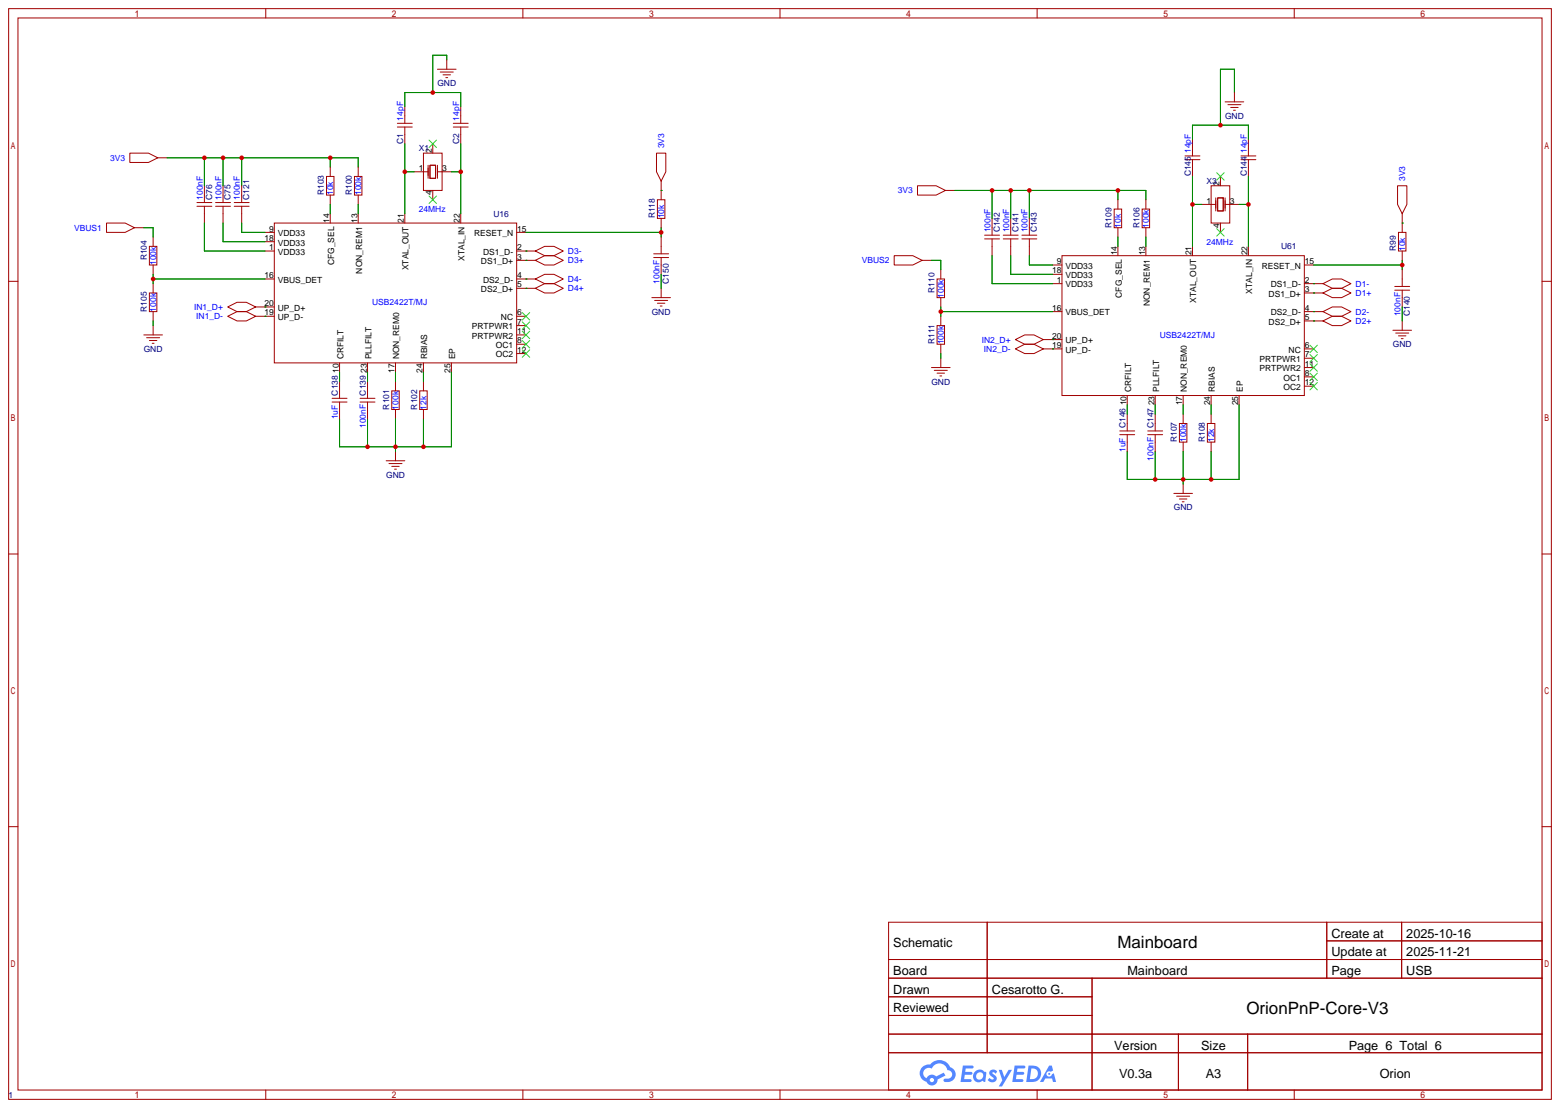
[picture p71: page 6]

Schematic | Mainboard | Create at | 2025-10-16

Update at | 2025-11-21

Board | Mainboard | Page | USB
Drawn | Cesarotto G. | OrionPnP-Core-V3
Reviewed

Version | Size | Page 6 Total 6
V0.3a | A3 | Orion

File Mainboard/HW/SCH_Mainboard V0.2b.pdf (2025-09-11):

VDD 72 | PB12 73 PB13 74 PB14 75 PB15 76 PD8 77 PD9 78 PD10 79 PD11 80 PD12 81 PD13 82 VSS 83 VDD 84 PD14 85 PD15 86 PG2 87 PG3 88 PG4 89 PG5 90 PG6 91 PG7 92 PG8 93 VSS 94 VDD 95 PC6 96 PC7 97 PC8 98 PC9 99 PA8 100 PA9 101 PA10 102 PA11 103 PA12 104 PA13 105 VCAP_2 106 VSS 107 VDD 108 PA14 109 PA15 110 PC10 111 PC11 112 PC12 113 PD0 114 PD1 115 PD2 116 PD3 117 PD4 118 PD5 119 VSS 120 VDD 121 PD6 122 PD7 123 PG9 124 PG10 125 PG11 126 PG12 127 PG13 128 PG14 129 VSS 130 VDD 131 PG15 132 PB3 133 PB4 134 PB5 135 PB6 136 PB7 137 BOOT0 138 PB8 139 PB9 140 PE0 141 PE1 142 PDR_ON 143 VDD 144
GND | GND OSC_OUT | OSC_IN

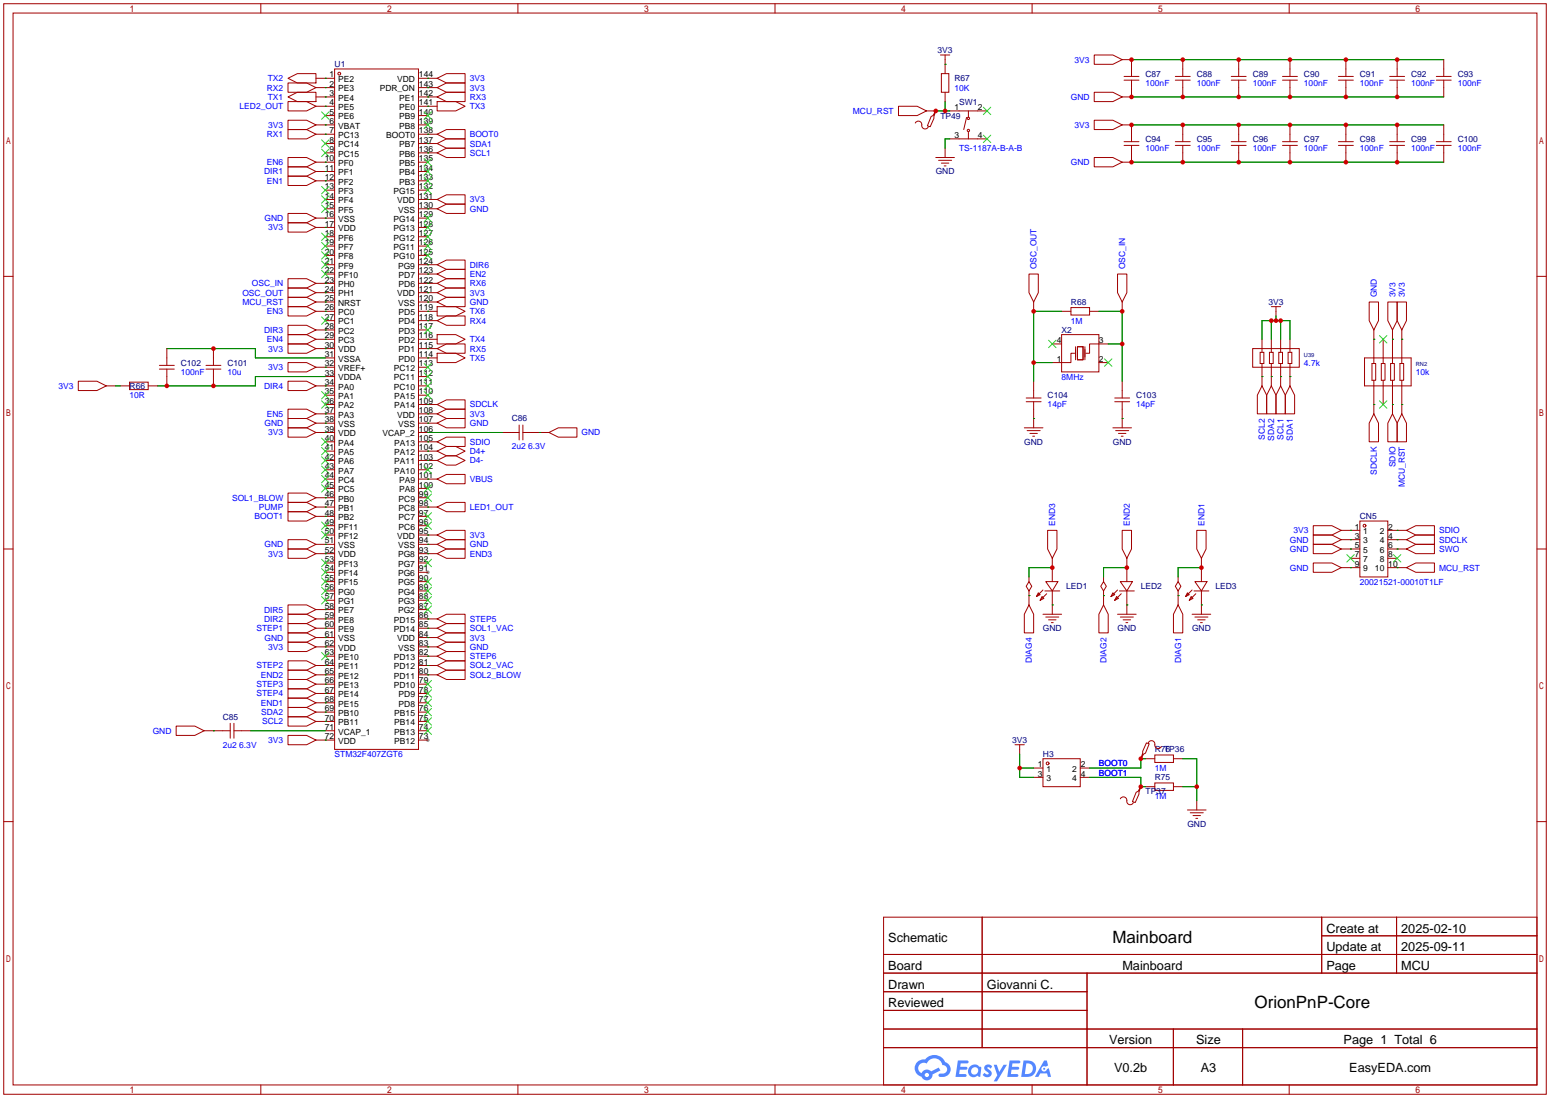
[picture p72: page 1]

Schematic | Mainboard | Create at | 2025-02-10

Update at | 2025-09-11

Board | Mainboard | Page | MCU
Drawn | Giovanni C. | OrionPnP-Core
Reviewed

Version | Size | Page 1 Total 6
V0.2b | A3 | EasyEDA.com

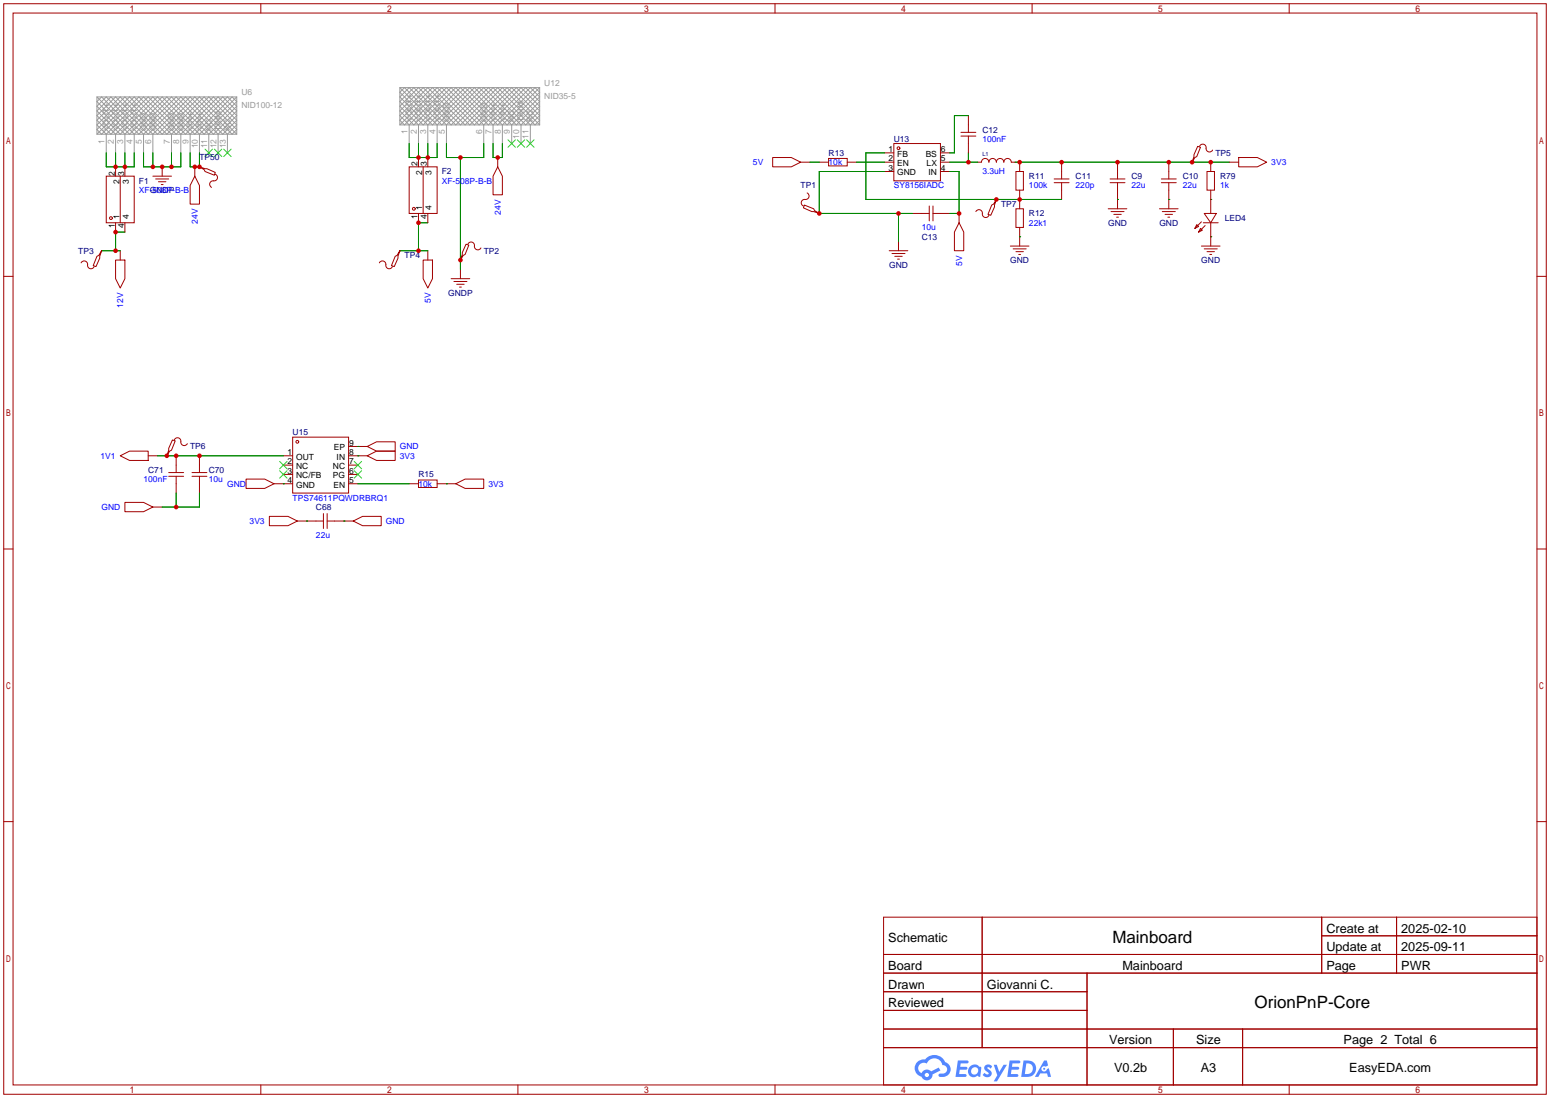
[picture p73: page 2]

Schematic | Mainboard | Create at | 2025-02-10

Update at | 2025-09-11

Board | Mainboard | Page | PWR
Drawn | Giovanni C. | OrionPnP-Core
Reviewed

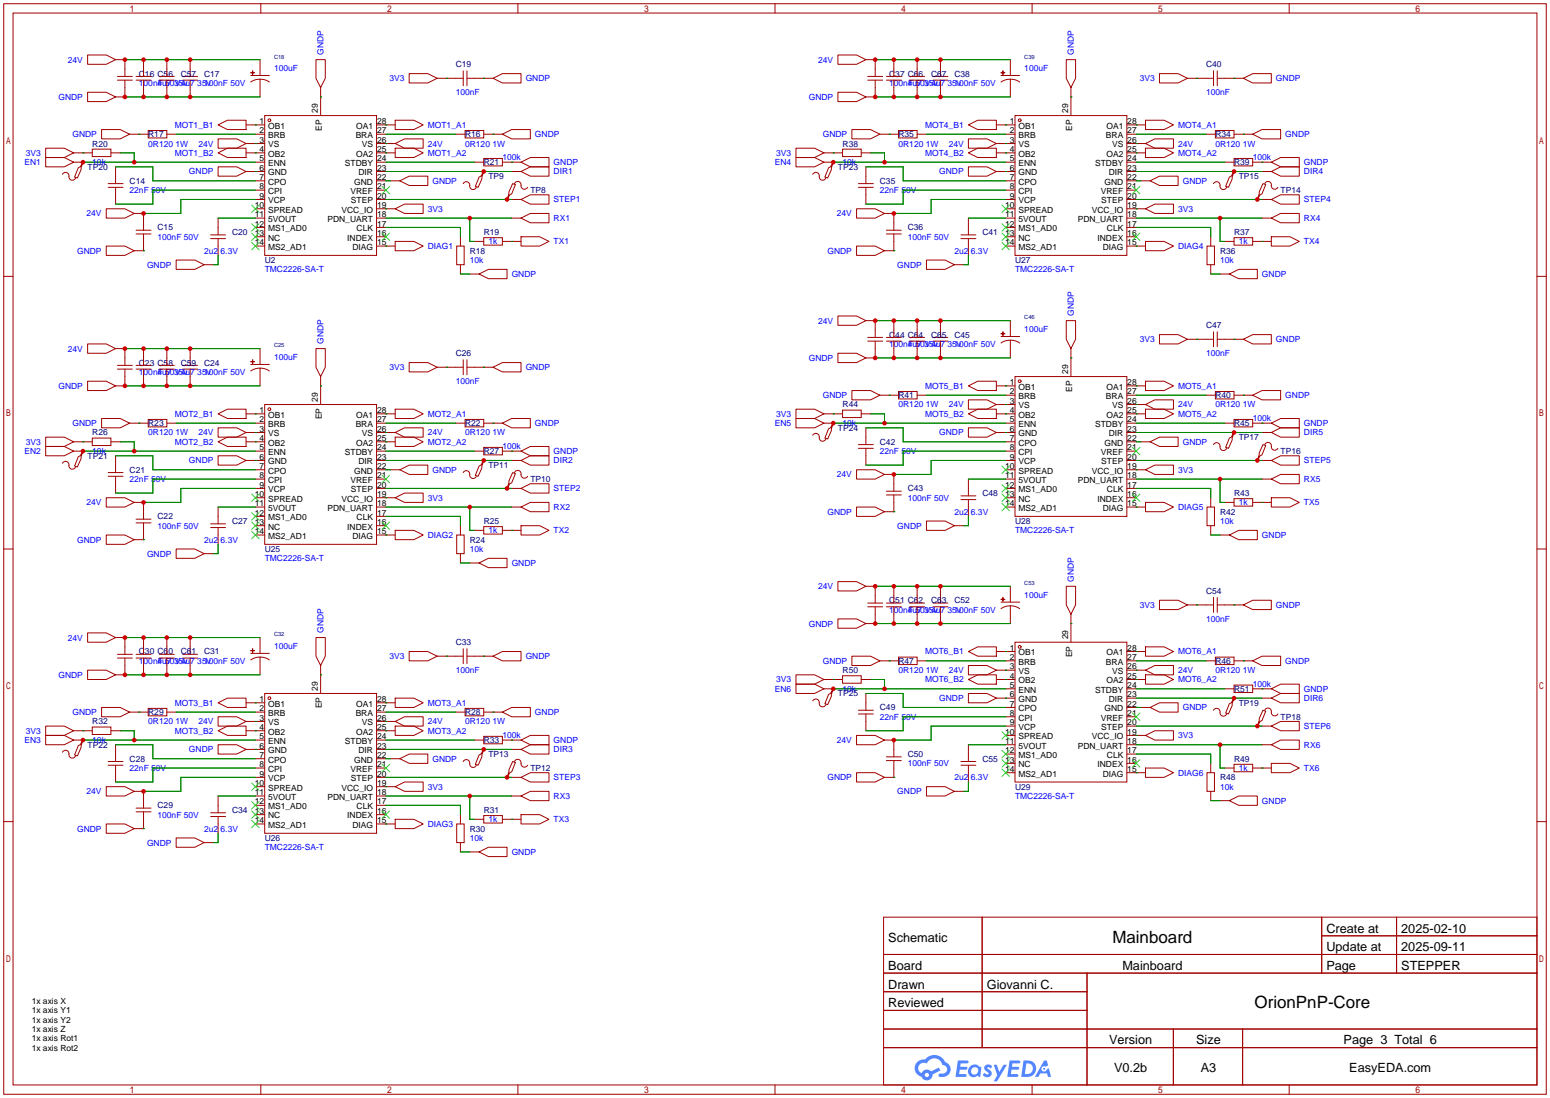
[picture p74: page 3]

Schematic | Mainboard | Create at | 2025-02-10

Update at | 2025-09-11

Board | Mainboard | Page | STEPPER
Drawn | Giovanni C. | OrionPnP-Core
Reviewed


Schematic | Mainboard | Create at | 2025-02-10

Update at | 2025-09-11

Board | Mainboard | Page | I/O
Drawn | Giovanni C. | OrionPnP-Core
Reviewed

# 5V_USR 5V5V_USR

## 1MGND


Schematic | Mainboard | Create at | 2025-02-10

Update at | 2025-09-11

Board | Mainboard | Page | CONN
Drawn | Giovanni C. | OrionPnP-Core
Reviewed


Schematic | Mainboard | Create at | 2025-02-10

Update at | 2025-09-11

Board | Mainboard | Page | USB
Drawn | Cesarotto G. | OrionPnP-Core
Reviewed

Version | Size | Page 6 Total 6
V0.2b | A3 | Orion

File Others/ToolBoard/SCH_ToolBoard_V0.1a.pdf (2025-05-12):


Schematic | ToolBoard | Create at | 2025-05-12

Update at | 2025-05-12

Board | ToolBoard | Page | P1
Drawn | Cesarotto G. | OrionPnP_ToolBoard
Reviewed

Version | Size | Page 1 Total 1
V0.1a | A4 | EasyEDA.com









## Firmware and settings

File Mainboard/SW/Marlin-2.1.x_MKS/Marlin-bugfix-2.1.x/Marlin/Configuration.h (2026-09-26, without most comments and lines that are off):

#pragma once
#define CONFIGURATION_H_VERSION 02010300
#define NO_EDGE_STEPPING_WARNING
#define NO_USER_FEEDBACK_WARNING
#define NO_AUTO_ASSIGN_WARNING
#define STRING_CONFIG_H_AUTHOR "Orion Project" // Original author or contributor.
#define CUSTOM_VERSION_FILE Version.h // Path from the root directory (no quotes)
  #define MOTHERBOARD BOARD_BTT_SKR_PRO_V1_2
#define SERIAL_PORT -1
#define BAUDRATE 250000
#define CUSTOM_MACHINE_NAME "Orion PnP"
#define X_DRIVER_TYPE  TMC2209
#define Y_DRIVER_TYPE  TMC2209
#define Z_DRIVER_TYPE  TMC2209
#define Y2_DRIVER_TYPE TMC2209
#define I_DRIVER_TYPE  TMC2209
#define J_DRIVER_TYPE  TMC2209
#define Y2_STEP_PIN       PE14  // = E0_STEP_PIN
#define Y2_DIR_PIN        PA0   // = E0_DIR_PIN
#define Y2_ENABLE_PIN     PC3   // = E0_ENABLE_PIN
#define Y2_SERIAL_TX_PIN  PD4   // = E0_SERIAL_TX_PIN
#define I_STEP_PIN        PD15  // = E1_STEP_PIN
#define I_DIR_PIN         PE7   // = E1_DIR_PIN
#define I_ENABLE_PIN      PA3   // = E1_ENABLE_PIN
#define I_SERIAL_TX_PIN   PD1   // = E1_SERIAL_TX_PIN
#define J_STEP_PIN        PD13  // = E2_STEP_PIN
#define J_DIR_PIN         PG9   // = E2_DIR_PIN
#define J_ENABLE_PIN       PF0  // = E2_ENABLE_PIN
#define J_SERIAL_TX_PIN   PD6   // = E2_SERIAL_TX_PIN
  #define AXIS4_NAME 'A' // :['A', 'B', 'C', 'U', 'V', 'W']
  #define AXIS4_ROTATES
  #define AXIS5_NAME 'B' // :['B', 'C', 'U', 'V', 'W']
  #define AXIS5_ROTATES
#define EXTRUDERS 0
#define TEMP_SENSOR_0 0
#define TEMP_SENSOR_1 0
#define TEMP_SENSOR_2 0
#define TEMP_SENSOR_3 0
#define TEMP_SENSOR_4 0
#define TEMP_SENSOR_5 0
#define TEMP_SENSOR_6 0
#define TEMP_SENSOR_7 0
#define DUMMY_THERMISTOR_998_VALUE  25
#define DUMMY_THERMISTOR_999_VALUE 100
#if TEMP_SENSOR_IS_MAX_TC(0)
  #define MAX31865_SENSOR_OHMS_0      100 // (Ω) Typically 100 or 1000 (PT100 or PT1000)
  #define MAX31865_CALIBRATION_OHMS_0 430 // (Ω) Typically 430 for Adafruit PT100; 4300 for Adafruit PT1000
#endif
#if TEMP_SENSOR_IS_MAX_TC(1)
  #define MAX31865_SENSOR_OHMS_1      100
  #define MAX31865_CALIBRATION_OHMS_1 430
#endif
#if TEMP_SENSOR_IS_MAX_TC(2)
  #define MAX31865_SENSOR_OHMS_2      100
  #define MAX31865_CALIBRATION_OHMS_2 430
#endif
#if TEMP_SENSOR_IS_MAX_TC(BED)
  #define MAX31865_SENSOR_OHMS_BED      100
  #define MAX31865_CALIBRATION_OHMS_BED 430
#endif
#if HAS_E_TEMP_SENSOR
  #define TEMP_RESIDENCY_TIME         10  // (seconds) Time to wait for hotend to "settle" in M109
  #define TEMP_WINDOW                  1  // (°C) Temperature proximity for the "temperature reached" timer
  #define TEMP_HYSTERESIS              3  // (°C) Temperature proximity considered "close enough" to the target
#endif
#if TEMP_SENSOR_BED
  #define TEMP_BED_RESIDENCY_TIME     10  // (seconds) Time to wait for bed to "settle" in M190
  #define TEMP_BED_WINDOW              1  // (°C) Temperature proximity for the "temperature reached" timer
  #define TEMP_BED_HYSTERESIS          3  // (°C) Temperature proximity considered "close enough" to the target
#endif
#if TEMP_SENSOR_CHAMBER
  #define TEMP_CHAMBER_RESIDENCY_TIME 10  // (seconds) Time to wait for chamber to "settle" in M191
  #define TEMP_CHAMBER_WINDOW          1  // (°C) Temperature proximity for the "temperature reached" timer
  #define TEMP_CHAMBER_HYSTERESIS      3  // (°C) Temperature proximity considered "close enough" to the target
#endif
#if TEMP_SENSOR_REDUNDANT
  #define TEMP_SENSOR_REDUNDANT_SOURCE    E1  // The sensor that will provide the redundant reading.
  #define TEMP_SENSOR_REDUNDANT_TARGET    E0  // The sensor that we are providing a redundant reading for.
  #define TEMP_SENSOR_REDUNDANT_MAX_DIFF  10  // (°C) Temperature difference that will trigger a print abort.
#endif
#define HEATER_0_MINTEMP   5
#define HEATER_1_MINTEMP   5
#define HEATER_2_MINTEMP   5
#define HEATER_3_MINTEMP   5
#define HEATER_4_MINTEMP   5
#define HEATER_5_MINTEMP   5
#define HEATER_6_MINTEMP   5
#define HEATER_7_MINTEMP   5
#define BED_MINTEMP        5
#define CHAMBER_MINTEMP    5
#define HEATER_0_MAXTEMP 275
#define HEATER_1_MAXTEMP 275
#define HEATER_2_MAXTEMP 275
#define HEATER_3_MAXTEMP 275
#define HEATER_4_MAXTEMP 275
#define HEATER_5_MAXTEMP 275
#define HEATER_6_MAXTEMP 275
#define HEATER_7_MAXTEMP 275
#define BED_MAXTEMP      150
#define CHAMBER_MAXTEMP  60
#define HOTEND_OVERSHOOT 15   // (°C) Forbid temperatures over MAXTEMP - OVERSHOOT
#define BED_OVERSHOOT    10   // (°C) Forbid temperatures over MAXTEMP - OVERSHOOT
#define COOLER_OVERSHOOT  2   // (°C) Forbid temperatures closer than OVERSHOOT
#define PIDTEMP           // See the PID Tuning Guide at https://reprap.org/wiki/PID_Tuning
    #define DEFAULT_KP  22.20
    #define DEFAULT_KI   1.08
    #define DEFAULT_KD 114.00
#define MAX_BED_POWER 255 // limits duty cycle to bed; 255=full current
#define MAX_CHAMBER_POWER 255 // limits duty cycle to chamber heater; 255=full current
  #define PID_FUNCTIONAL_RANGE 20 // If the temperature difference between the target temperature and the actual temperature
#define EXTRUDE_MAXLENGTH 200
#define THERMAL_PROTECTION_HOTENDS // Enable thermal protection for all extruders
#define THERMAL_PROTECTION_BED     // Enable thermal protection for the heated bed
#define THERMAL_PROTECTION_CHAMBER // Enable thermal protection for the heated chamber
#define THERMAL_PROTECTION_COOLER  // Enable thermal protection for the laser cooling
#define ENDSTOPPULLUPS
#define X_MIN_ENDSTOP_HIT_STATE HIGH  // NC endstop: open (HIGH) when triggered
#define X_MAX_ENDSTOP_HIT_STATE HIGH
#define Y_MIN_ENDSTOP_HIT_STATE HIGH  // NC endstop: open (HIGH) when triggered
#define Y_MAX_ENDSTOP_HIT_STATE HIGH  // NC endstop: open (HIGH) when triggered
#define Z_MIN_ENDSTOP_HIT_STATE LOW   // NO endstop: closed (LOW) when triggered
#define Z_MAX_ENDSTOP_HIT_STATE HIGH
#define I_MIN_ENDSTOP_HIT_STATE LOW   // Fake stop pin is unconnected/pullup HIGH → LOW = not hit
#define I_MAX_ENDSTOP_HIT_STATE HIGH
#define J_MIN_ENDSTOP_HIT_STATE LOW   // Fake stop pin is unconnected/pullup HIGH → LOW = not hit
#define J_MAX_ENDSTOP_HIT_STATE HIGH
#define K_MIN_ENDSTOP_HIT_STATE HIGH
#define K_MAX_ENDSTOP_HIT_STATE HIGH
#define U_MIN_ENDSTOP_HIT_STATE HIGH
#define U_MAX_ENDSTOP_HIT_STATE HIGH
#define V_MIN_ENDSTOP_HIT_STATE HIGH
#define V_MAX_ENDSTOP_HIT_STATE HIGH
#define W_MIN_ENDSTOP_HIT_STATE HIGH
#define W_MAX_ENDSTOP_HIT_STATE HIGH
#define Z_MIN_PROBE_ENDSTOP_HIT_STATE HIGH
#define DEFAULT_AXIS_STEPS_PER_UNIT   { 100, 100, 80, 8.889, 8.889 }
#define EDITABLE_STEPS_PER_UNIT
#define DEFAULT_MAX_FEEDRATE          { 510, 510, 80, 1080, 1080 }
#define DEFAULT_MAX_ACCELERATION      { 1700, 1700, 50, 500, 500 }
#define DEFAULT_ACCELERATION          1500    // X, Y, Z and E acceleration for printing moves
#define DEFAULT_RETRACT_ACCELERATION  1500    // E acceleration for retracts
#define DEFAULT_TRAVEL_ACCELERATION   1500    // X, Y, Z acceleration for travel (non printing) moves
  #define JUNCTION_DEVIATION_MM 0.013 // (mm) Distance from real junction edge
  #define JD_HANDLE_SMALL_SEGMENTS    // Use curvature estimation instead of just the junction angle
#define X_ENABLE_ON LOW
#define Y_ENABLE_ON LOW
#define Z_ENABLE_ON LOW
#define I_ENABLE_ON LOW
#define J_ENABLE_ON LOW
#define DISABLE_OTHER_EXTRUDERS   // Keep only the active extruder enabled
#define INVERT_X_DIR true
#define INVERT_Y_DIR true
#define INVERT_Z_DIR true
#define INVERT_I_DIR false
#define INVERT_J_DIR false
#define INVERT_E0_DIR false
#define INVERT_E1_DIR false
#define INVERT_E2_DIR false
#define INVERT_E3_DIR false
#define INVERT_E4_DIR false
#define INVERT_E5_DIR false
#define INVERT_E6_DIR false
#define INVERT_E7_DIR false
#define Z_CLEARANCE_FOR_HOMING  0   // (mm) Minimal Z height before homing (G28) for Z clearance above the bed, clamps, ...
#define XY_AFTER_HOMING { 2,408}  // (mm) Move to an XY position after homing (and raising Z)
#define X_HOME_DIR -1
#define Y_HOME_DIR  1
#define Z_HOME_DIR -1
#define I_HOME_DIR  0
#define J_HOME_DIR  0
#define X_BED_SIZE 331
#define Y_BED_SIZE 410
#define X_MIN_POS -1
#define Y_MIN_POS 1
#define Z_MIN_POS -45
#define X_MAX_POS 330
#define Y_MAX_POS 411
#define Z_MAX_POS 45
#define I_MIN_POS -360
#define I_MAX_POS  360
#define J_MIN_POS -360
#define J_MAX_POS  360
#define MANUAL_X_HOME_POS -1
#define MANUAL_Y_HOME_POS 411
#define MANUAL_Z_HOME_POS -45
#define HOMING_FEEDRATE_MM_M { (10*60), (10*60), (12*60), (30*60), (30*60) }
#define VALIDATE_HOMING_ENDSTOPS
#define EEPROM_CHITCHAT       // Give feedback on EEPROM commands. Disable to save flash.
#define EEPROM_BOOT_SILENT    // Keep M503 quiet and only give errors during first load
#define HOST_KEEPALIVE_FEATURE        // Disable this if your host doesn't like keepalive messages
#define DEFAULT_KEEPALIVE_INTERVAL 2  // Number of seconds between "busy" messages. Set with M113.
#define BUSY_WHILE_HEATING            // Some hosts require "busy" messages even during heating
#define PREHEAT_1_TEMP_HOTEND 180
#define PREHEAT_1_TEMP_BED     70
#define PREHEAT_1_TEMP_CHAMBER 35
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

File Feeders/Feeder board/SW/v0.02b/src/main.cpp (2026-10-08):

#include <Arduino.h>
#include <Wire.h>
#include <EEPROM.h>
#include <math.h>
#include <Adafruit_NeoPixel.h>
#include "pins_config.h"

#ifdef TAPJIG_TEST
// TAP-Jig TEST build (env atmega328pb_isp_test, -DTAPJIG_TEST): the same
// firmware plus a few commands only the test-and-program jig needs, and
// with the autonomous behaviour that would fight a test switched off (no
// boot homing, no button actions - buttons are only reported, the status RGB
// can be held by the jig). The production build (default env) contains none
// of this. See ../tools/TAPJIG.md.
#include <avr/wdt.h>
uint8_t mcusrAtBoot __attribute__((section(".noinit")));
void captureMcusr(void) __attribute__((naked, used, section(".init3")));
void captureMcusr(void) { mcusrAtBoot = MCUSR; MCUSR = 0; wdt_disable(); }
bool testRgbHold = false;
#endif

/*
  v0.02b - forked from v0.02. Adds:
  - Status RGB brightness is runtime-adjustable and persisted
    (LedCfg, LEDBRIGHT <1-255> / CMD_SET_LED_BRIGHTNESS), default much lower
    than before - visible without the current draw.
  - Peel is tied to the feed distance. PeelRate (ms of peel per mm of
    sprocket travel, PEELRATE <ms/mm> / CMD_SET_PEEL_RATE) makes a feed run
    the peel motor for the same distance AFTER the sprocket has advanced,
    and a backwards seat (snapToToothBackward) run the peel motor in
    reverse BEFORE the sprocket goes back, by the same amount. Unset rate
    = no coupling (v0.02 behaviour).
  - Buttons: three modes, SW1 = forward / SW2 = reverse in each - feed only
    (blue, boot default), peel only (orange), feed+peel (green). SW1+SW2
    together step to the next. Peel-only drops back to feed-only after
    PEEL_MODE_IDLE_TIMEOUT_MS.
  - Status RGB flashes green when a frame addressed to this feeder arrives.
  - CMD_FEED_BACK: the mirror of CMD_FEED_NEXT (peel reversed first).
  See project.md.

  v0.02 - forked from v0.01a. Adds, on top of everything below:
  - Per-feeder peel calibration: the peel run time that suits THIS
    feeder's mechanics is stored in the ATmega's internal EEPROM
    (PeelCal), set with CMD_SET_PEEL_TIME / PEELCAL <ms>, read with
    CMD_GET_PEEL_TIME, and used by CMD_PEEL with only a direction byte
    (PEELRUN on the debug port). Independent of the loaded component, so
    it survives component changes and RESETCFG.
  - CMD_JOG: relative move over the bus in 0.1mm units (signed), replying
    with the new raw angle - lets a host seat a sprocket hole without the
    debug port, then CMD_ZERO_HERE.
  - AT24C02 support: a plain AT24C02 has no factory serial page (0x58),
    which is why CMD_GET_SERIAL NACKed on a board that otherwise talks
    to the EEPROM fine. CMD_I2C_SCAN shows what actually answers on the
    bus; CMD_SET_SERIAL programs a 16-byte serial into the normal EEPROM
    (read back and verified), used whenever no factory serial exists.
  - AT24 writes are now split on 8-byte page boundaries (the AT24C02
    wraps within a page, so a write crossing one corrupts the start of
    that page).

  v0.01a - forked from beta1 at the point PIN_5V_READY/PIN_485_RELAY were
  corrected (point 6 below). First MAJOR-version release: the stepping
  stone going forward, not another bench-iteration alpha/beta. Only
  change from that beta1 state: the bench-only auto-run test aids
  (runDebugSelfTest(), runRelayButtonTest()) are commented out of
  setup() rather than running unconditionally on every boot - see their
  call sites below. Both functions are still defined and still reachable
  on demand (SELFTEST debug command, RELAY ON/OFF), just not forced on a
  release build's every power-up. The real safety gate -
  waitFor5vStableAndEngageRelay(), which the relay only ever actually
  engages through - is untouched.

  Also v0.01a: status RGB = yellow booting / blue ready / red error /
  purple moving; peel motor runnable on its own (peel-only button mode, PEEL, CMD_PEEL)
  for tape tensioning; compact debug output (TRACE off by default); no
  String class in the debug parser. See project.md items 5-9.

  PIN_5V_READY's divider still isn't correct on real hardware as of this
  fork (the PCB needs the 4.7k/1k resistor swap - see beta1/project.md,
  "Open questions") - kept implemented anyway rather than stripped out,
  since the logic itself is right and just needs the matching hardware
  fix.

  Below is beta1's own history at the point of the fork, describing the
  additions this inherits from alpha03:

  1. PIN_I_MON (A6/PE2) - analog, the IMON output of a TPS26600 eFuse on
     the 12V rail (RIMON=309k, 1%), a voltage proportional to load
     current: ~4.07V at the 200mA design max load, linear through the
     origin. Read with the default AVCC reference; see the "Power
     sequencing" section below and readIMonMilliamps(). TPS26600's EN/
     FLT# pins are NOT wired to the MCU - it can't be, since the MCU only
     runs once the eFuse is already on, so there's no fault state where
     firmware could still be reading a pin to report it.
  2. PIN_5V_READY (A2/PC2) - analog, 5V rail via an external 4.7k/1k
     divider (4.7k to the rail, 1k to GND - picked over 10k/1k for ~2x
     the ADC resolution, see pins_config.h). Read against the ATmega's
     INTERNAL 1.1V reference, not the default - see "Power sequencing"
     for why the default reference cannot work for this specific signal.
  1b. Both of the above convert their raw ADC reading to a real-world
     mA/mV through AnalogCalibration, a single (raw, real-world) point per
     signal, persisted in the ATmega's internal EEPROM and hand-settable
     on the bench with the CALI/CALV debug commands against a real
     ammeter/multimeter - useful once a bed-of-nails test jig exists to
     make that fast. Falls back to the factory-calculated defaults
     (derived from the same numbers as points 1/2 above) until then. See
     the struct's comment further down for why this is deliberately not
     folded into FeederConfig or FeederHardwareInfo. estimateI5vMilliamps()
     also derives a rough 5V-rail current estimate from these two readings
     (IMON + 12V-nominal power balance) - debug/bench convenience only,
     not a real measurement; see that function's comment for what it
     ignores.
  3. PIN_485_RELAY (A7/PE3) - a MOSFET-driven relay coil that physically
     connects/disconnects this feeder's RS485 lines from the shared bus.
     Held disconnected until PIN_5V_READY has read stable for
     RELAY_READY_STABLE_MS, so a feeder that's still mid-power-up can't
     electrically disturb a bus other feeders/the host are already using.
  4. Motor A's effective direction defaults to inverted (invertMotorA =
     true) - the final board's DRV8833 OUT1/OUT2 (motor-output side, not
     the MCU-to-driver AIN side) are swapped relative to the bench units
     this control loop was tuned against. Net effect on firmware is the
     same as any other "wired backwards" case.
  5. PIN_AIN1/PIN_AIN2 <-> PIN_BIN1/PIN_BIN2 are swapped in pins_config.h
     relative to alpha01-03 - the first real beta1 bench test found that
     commanding "motor A" (closed-loop feed/sprocket logic) actually
     moved the peel motor instead, i.e. the two DRV8833 channels drive
     the opposite motor connectors from what alpha01-03's pin numbers
     assumed. Different bug from point 4's direction inversion - see
     pins_config.h for the fix and why invertMotorA=true above is
     unverified against it (validated against the old channel assignment,
     not this one).
  6. PIN_5V_READY and PIN_485_RELAY (points 2/3 above) were originally
     speced backwards: PE3/A7 was PIN_5V_READY (an analog input) and
     PIN_485_RELAY was on D13/PB5. Real hardware has it the other way -
     PE3/A7 is the relay drive (digital OUTPUT), and PIN_5V_READY is on
     A2/PC2 instead. D13/PB5 is now unused again. Also broke
     seedSessionNonce()'s entropy source, which assumed A2 was a floating
     ADC pin - it's PIN_5V_READY now, a real signal, so that XOR was
     dropped (see its own comment).

  Points 5 and 6 are the only entries on this list confirmed against real
  beta1 hardware so far; the rest (new pins otherwise, the OUT1/OUT2
  direction swap) are still ahead of any board built so far - same
  situation alpha03 was already in for its own additions, firmware
  written for a schematic revision that doesn't exist as a built board
  yet.

  Also carries forward everything alpha03 added on top of alpha02: AT24CS02
  I2C EEPROM + factory serial number (FeederHardwareInfo now lives there,
  not the ATmega's internal EEPROM), CMD_GET_SERIAL. See alpha03/project.md
  for that reasoning in full.

  Everything else (SW1 closed-loop / SW2 open-loop, RS485 transport,
  addressing/discovery, tape-zero/distance-based motion, FeederConfig) is
  unchanged from alpha01/02 - see those projects' project.md files for the
  full design rationale, and alpha01's for the Modbus feasibility
  evaluation.

  What beta1 deliberately does NOT do yet (inherited from alpha01-03):
  - No interrupt-driven UART RX. Bytes are polled in loop(). Since
    moveToAngle() blocks synchronously for up to MOVE_TIMEOUT_MS, and
    USART0 only has a 2-byte hardware buffer, any bus traffic arriving
    mid-move today WILL be lost. Fine for bench-testing in isolation, but
    must be fixed (RX ISR + ring buffer) before real bus traffic coexists
    with motion - see project.md "Open questions".
  - No Modbus RTU. The frame format below is a placeholder.
*/

// ---------------------------
// AS5600 registers
// ---------------------------
const uint8_t AS5600_ADDR = 0x36;
const uint8_t AS5600_REG_STATUS = 0x0B;
const uint8_t AS5600_REG_ANGLE = 0x0E; // + 0x0F (filtered/hysteresis)
const uint8_t AS5600_REG_AGC = 0x1A;
const uint8_t AS5600_REG_MAGNITUDE = 0x1B; // + 0x1C

// ---------------------------
// Wheel geometry
//
// Sprocket holes on carrier tape are spaced 4mm apart regardless of tape
// width (EIA-481 standard) - one sprocket tooth engages one hole, so one
// tooth of travel is always 4mm of tape, independent of what's on the
// tape. Everything below derives from that one physical constant plus the
// wheel's tooth count.
// ---------------------------
const int TOOTH_COUNT = 40;
const float DEG_PER_TOOTH = 360.0f / TOOTH_COUNT;       // 9.0 deg
const float DEG_PER_HALF_TOOTH = DEG_PER_TOOTH / 2.0f;  // 4.5 deg
const float SPROCKET_HOLE_PITCH_MM = 4.0f;              // EIA-481: fixed, all tape widths
const float DEG_PER_MM = DEG_PER_TOOTH / SPROCKET_HOLE_PITCH_MM; // 2.25 deg/mm

// Fixed mechanical offset from "a sprocket tooth is seated" to "the pick
// window/camera position" - purely geometric (PCB/frame layout), so it's
// the same on every feeder of this exact design, not per-unit or
// per-component. Measure ONCE with a camera on a reference unit (jog with
// MOVEMM to find it), then hardcode the result here - see project.md
// "Tape zero calibration, v2". Left at 0.0 until that measurement exists;
// ZEROHERE/GOTOZERO will be off by this amount until it's filled in.
const float PICK_OFFSET_MM = 0.0f; // TODO: measure once, see comment above

// ---------------------------
// Motion / control tuning (unchanged from TestBench03/04)
// ---------------------------
const float ANGLE_TOLERANCE_DEG = 0.30f;
const float CREEP_THRESHOLD_DEG = 3.0f;
const int   FAST_DUTY = 110;
const int   DEFAULT_MIN_MOVE_DUTY = 60;

const unsigned long MOVE_TIMEOUT_MS = 6000;
const unsigned long STALL_TIMEOUT_MS = 800;
const float STALL_MOVE_THRESHOLD_DEG = 0.15f;

// SW2/motor B open-loop jog (see file header - motor B has no encoder on
// this design, so there's no closed-loop equivalent to fall back to).
// Peel motor is also run on its own to tension the cover tape: in peel-only
// button mode SW1/SW2 run it forward/reverse for as long as the button is
// held (PEEL_HOLD_MAX_MS safety cap), PEEL debug command / CMD_PEEL run it
// for a set time.
const int   PEEL_DUTY = FAST_DUTY;
const unsigned long PEEL_HOLD_MAX_MS = 10000;
const unsigned long PEEL_CMD_MAX_MS = 5000;
const unsigned long PEEL_CAL_MIN_MS = 10;

const bool BUTTONS_ACTIVE_LOW = true;
const unsigned long DEBOUNCE_MS = 20;

// Feed direction (motor A). invertMotorA flips the motor drive AND the
// AS5600 angle together - flipping only one of them would make the closed
// loop drive away from its target and never settle. Logical "forward"
// (increasing angle) always means "feed tape forward".
//
// Base state (invertMotorA = false): motor drive inverted, encoder
// normal - the combination the loop was validated with, and confirmed on
// the real v0.01a board to settle fine but feed the tape BACKWARDS.
// invertMotorA = true flips both from there (motor not inverted, encoder
// mirrored), so it's the default. INVERTA / CMD_SET_INVERT_DIR still flip
// it at runtime (RAM-only) - flipping mirrors the angle, so any saved tape
// zero no longer points at the same hole.
//
// invertMotorB is a plain motor-polarity flip (peel motor has no encoder).
constexpr bool MOTOR_A_BASE_INVERT = true;
bool invertMotorA = true;
bool invertMotorB = false;

// Both UARTs share the same 8MHz internal RC oscillator (~2% tolerance),
// so both stay at 9600 - see TestBench04/project.md for why 115200 is
// unreliable here. RS485_BAUD also doubles as the bus's initial working
// assumption; revisit once a crystal is on the board or Modbus baud is
// decided.
const unsigned long RS485_BAUD = 9600;
const unsigned long DEBUG_BAUD = 9600;

const uint32_t I2C_CLOCK_HZ = 100000;

// ---------------------------
// Zero-point (still-duty) calibration tuning
// ---------------------------
const int   CAL_START_DUTY = 15;
const int   CAL_MAX_DUTY = 200;
const int   CAL_STEP_DUTY = 5;
const unsigned long CAL_STEP_MS = 60;
const float CAL_MOVE_THRESHOLD_DEG = 0.6f;
const int   CAL_MARGIN_DUTY = 6;
const unsigned long CAL_RESTORE_TIMEOUT_MS = 4000;

// ---------------------------
// Addressing (see project.md "Addressing scheme", v2)
//
// The bus address is disposable and RAM-only: every boot starts
// unaddressed (0x00) and re-earns an address via CMD_DISCOVER, so nothing
// about the address survives a power cycle or needs EEPROM at all. What
// DOES persist is the feeder's loaded-component config (below) - that's
// the thing worth not losing on reinsertion, not the address.
// ---------------------------
constexpr uint8_t ADDR_UNASSIGNED = 0x00; // also the broadcast address
constexpr uint8_t ADDR_MIN = 1;
constexpr uint8_t ADDR_MAX = 247;

uint8_t busAddress = ADDR_UNASSIGNED;
uint16_t sessionNonce = 0; // random per boot, only used to disambiguate discovery replies

bool isValidAssignedAddress(uint8_t a) {
  return a >= ADDR_MIN && a <= ADDR_MAX;
}

// Seeds from boot-to-boot jitter in micros(). Used to XOR in an
// analogRead(A2) too, on the assumption A2 was a floating/unconnected
// ADC pin - it isn't: A2 is PIN_5V_READY, a real connected signal (see
// pins_config.h), and every other analog-capable pin on this board
// (A0-A7) is spoken for as well (buttons, I2C, IMON, relay drive) - none
// left floating to harvest noise from. Not cryptographically unique -
// doesn't need to be. It only has to avoid colliding with whichever
// other feeders happen to be replying to the same CMD_DISCOVER round,
// and a fresh value is drawn every boot anyway.
void seedSessionNonce() {
  randomSeed(micros());
  sessionNonce = (uint16_t)random(0, 65536);
}

// ---------------------------
// Persistent per-feeder config (EEPROM) - what SHOULD survive reinsertion.
//
// componentId: OpenPnP part id (see openPnP/parts.xml) currently loaded.
// tapeZeroRaw: AS5600 raw angle (0-4095) marking the current tape's
//   "ready" pocket position - meaningless across a component change, since
//   a different reel is now engaged with the sprocket at an arbitrary
//   rotational offset.
// feedHalfTeeth: advance per pick, in half-tooth (4.5 deg / 2mm) units.
//   2 = 4mm/1 tooth (standard EIA-481 sprocket pitch, "raw"), 1 = 2mm
//   ("fine", sub-tooth pitch), anything else = "custom" for wider-pitch
//   parts (8/12/16/24mm reels etc). Not three separate stored presets -
//   just one active step size; changing which preset is "active" is a
//   host/UI choice about what value to write here.
//
// All three reset to "unset" together whenever componentId changes (a
// different reel means the old zero/step are meaningless), or on an
// explicit manual reset - never on a bare reinsertion of the same
// component. NOT to be confused with calibrateZero()/stillDutyMax below,
// which is the DRV8833 motor-duty characterization - electrical, unrelated
// to which tape is loaded, and still re-run on every boot regardless.
// ---------------------------
struct FeederConfig {
  uint16_t componentId;
  uint16_t tapeZeroRaw;
  uint8_t feedHalfTeeth;
  uint8_t crc;
};

constexpr int EEPROM_CONFIG_LOCATION = 0;
constexpr uint16_t COMPONENT_ID_UNSET = 0xFFFF;
constexpr uint16_t TAPE_ZERO_UNSET = 0xFFFF;
constexpr uint8_t FEED_HALF_TEETH_UNSET = 0xFF;
constexpr uint8_t FEED_HALF_TEETH_STANDARD = 2; // 4mm / 1 tooth, EIA-481 default

FeederConfig cfg;

uint8_t crc8(const uint8_t *data, uint8_t len); // fwd decl, defined below

uint8_t configCrc(const FeederConfig &c) {
  return crc8(reinterpret_cast<const uint8_t *>(&c), sizeof(FeederConfig) - 1);
}

void resetFeedConfig() {
  cfg.tapeZeroRaw = TAPE_ZERO_UNSET;
  cfg.feedHalfTeeth = FEED_HALF_TEETH_UNSET;
}

void saveConfig() {
  cfg.crc = configCrc(cfg);
  EEPROM.put(EEPROM_CONFIG_LOCATION, cfg); // EEPROM.put only rewrites changed bytes
}

void loadConfig() {
  EEPROM.get(EEPROM_CONFIG_LOCATION, cfg);
  if (cfg.crc != configCrc(cfg)) {
    // Blank/garbage EEPROM (factory-fresh board) - start fully unset.
    cfg.componentId = COMPONENT_ID_UNSET;
    resetFeedConfig();
    saveConfig();
  }
}

// ---------------------------
// Analog calibration - beta1 only. IMON (TPS26600) and 5V_READY are both
// resistor-divider/current-mirror signals whose actual scale depends on
// real component tolerances on THIS physical board, not just the nominal
// datasheet/calculator math baked into the constants below. Each is
// stored as a single (raw ADC, real-world value) point and the firmware
// assumes linear-through-the-origin from there (true for both signals'
// underlying hardware - a resistor divider and a current-mirror IMON
// output). Hand calibration (CALI/CALV debug commands) overwrites the
// point with one measured against a real ammeter/multimeter on the bench
// - e.g. once a bed-of-nails test jig exists to make that fast and
// repeatable. Independent of FeederConfig - a component change or
// RESETCFG must never touch this, same reasoning as FeederHardwareInfo.
// Lives in the ATmega's own internal EEPROM (not the AT24CS02) - it's
// bench/electrical calibration data for this board's analog frontend,
// not part of the AT24CS02's tape-width/serial-number "what this unit
// physically is for tape handling" role, and calibrating it doesn't
// require an AT24CS02 to even be populated.
// ---------------------------
struct AnalogCalibration {
  uint16_t imonCalRaw; // PIN_I_MON raw ADC reading at imonCalMa (default reference)
  uint16_t imonCalMa;  // actual measured current (mA) at imonCalRaw, from a bench ammeter
  uint16_t v5vCalRaw;  // PIN_5V_READY raw ADC reading at v5vCalMv (internal 1.1V reference)
  uint16_t v5vCalMv;   // actual measured 5V-rail voltage (mV) at v5vCalRaw, from a bench multimeter
  uint8_t crc;
};

constexpr int EEPROM_ANALOG_CAL_LOCATION = 16; // gap left after EEPROM_CONFIG_LOCATION, same pattern alpha02 used for hw info
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
void loop() {
  const unsigned long now = millis();
  const bool magnet = magnetDetected();

  // Status RGB: blue = ready, red = error (no magnet / driver fault).
  // Purple (moving) is set inside the move/peel functions themselves and
  // gets repainted here on the next iteration once they return.
#ifdef TAPJIG_TEST
  if (testRgbHold) { /* the jig is driving the RGB */ }
  else
#endif
  if ((long)(rxFlashUntilMs - now) > 0) { /* bus-activity flash still showing */ }
  else if (magnet && digitalRead(PIN_nFAULT) != LOW) ledReady();
  else ledError();

  if (now - lastHeartbeatMs >= 3000) {
    lastHeartbeatMs = now;
    // Without a magnet the AS5600 angle is noise - skip the check and drop
    // the baseline so the next real reading starts a fresh comparison.
    if (magnet) {
      const float angleNow = readAngleDeg();
      if (lastHeartbeatAngleValid && fabsf(angleErrorDeg(angleNow, lastHeartbeatAngle)) > 1.0f) {
        Serial1.println(F("WARN: wheel moved while idle"));
      }
      lastHeartbeatAngle = angleNow;
      lastHeartbeatAngleValid = true;
    } else {
      lastHeartbeatAngleValid = false;
    }
  }

  if (digitalRead(PIN_nFAULT) == LOW) {
    brakeMotorA();
    brakeMotorB();
    digitalWrite(PIN_FAULT_LED, HIGH);
    if (now - lastFaultLogMs >= 2000) {
      lastFaultLogMs = now;
      Serial1.println(F("FAULT: DRV8833 nFAULT, motors braked"));
    }
    return;
  }
  digitalWrite(PIN_FAULT_LED, LOW);

#ifndef TAPJIG_TEST // test build: no autonomous motor moves, no button actions (inputs are read over the bus)
  checkHoming(); // no-op once homingDone; see its own comment for the boot-delay/stagger + magnet-stability gate

  handleButtons(lastSw1EdgeMs);
#endif
  motorsSleepIfIdle();

  rs485Poll();

  while (Serial1.available()) {
    const char c = toupper(Serial1.read());
    if (c == '\n' || c == '\r') {
      while (debugLineLen > 0 && debugLineBuf[debugLineLen - 1] == ' ') debugLineLen--;
      if (debugLineLen > 0) {
        debugLineBuf[debugLineLen] = '\0';
        handleDebugLine(debugLineBuf);
        debugLineLen = 0;
      }
    } else if ((c != ' ' || debugLineLen > 0) && debugLineLen < DEBUG_LINE_MAX) {
      debugLineBuf[debugLineLen++] = c; // leading spaces dropped, overlong lines truncated
    }
  }
}

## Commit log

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2025-04-17 Updated documentation for V0.2a
    Updated documentation for V0.2a
    Changed changelog to reflect this
    Updated debug with fix to USB COM port of STM32
    [BOM_Mainboard V0.2a.xlsx, PNP_Mainboard V0.2a.csv]
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2025-05-06 Updated BOM
    Added the first few printed components
    Added 2 bracing beams to help with bottom component assembly and work surface stability
    [Hardware BOM.ods]
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2025-05-09 Feeder CAD update
    - Fixed collision between feeder body and worm gear
    - Exported f3z file of the project
    [UpperBody.3mf, UpperBody.stl]
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2025-05-30 Updated harness docs
    - Added connectors and cables to the harness
    - Fixed PE cables not showing correctly the two colors
    [MACHINE.bom.tsv, MACHINE.yaml]
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2025-07-04 Updated 3d files
    [Head chain mount] Fixed issue where chain would flex enough to force a breakage on PLA or other brittle materials.
    [Head chain mount] Moved the chain mount location a bit more toward the front for improved routing
    [Y stepper mounts] revised stepper mounts to reduce torquing the pieces. Needs manual tensioning but should suffice for PnP use.
    [Pump rings] Started export of pump mount
    [Frame_pump_ring_a.stl, Head_Chain_mount.stl, Y_motor_bracket.stl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]
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2025-07-08 Updated 3d models
    [Pump brackets] brackets to hold the pump in place
    [Pump rings] rings to be printed in TPU to dampen noise from the pump
    [Vacuum tank] Buffer tank for the vacuum system
    [Frame_Pump_bracket_a.stl, Frame_Pump_bracket_b.stl, Frame_pump_ring_b.stl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]
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2026-03-02 Renamed Marlin Build
    - Renamed Marlin for Core board
    - Added marlin bugfix to test on MKS
    - Moved binaries in dedicated folders
    [Configuration.h, Configuration_adv.h, esp32.csv]
2026-03-02 Renamed folders and edited build
    - Renamed folder for Powershell path issues
    - Edited configuration for MKS Gen V1.4 to start testing kinematics
    [Configuration.h, Configuration_adv.h, esp32.csv]
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2026-08-21 TestBench03: add motor B sync/PEEL/continuous feed, fix direction inversion
    Front motor now triggers a rear peel motor (open-loop, fixed on/off) after
    any move that ends up real-world-forward, timed to match how long that
    move took. Jog buttons gained long-press (continuous feed until released)
    and forward-button double-tap (manual PEEL) gestures.
    Also fixes a real-world/raw-angle direction mismatch: increasing the
    AS5600 reading was the mechanism's reverse, not forward. This is handled
    via RAW_ANGLE_INCREASE_IS_REVERSE + TOOTH_STEP_DEG at the target-angle
    translation layer, keeping the motor/encoder relationship
    (INVERT_DIRECTION) untouched so the closed loop keeps converging instead
    of fi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
    [drv8833_as5600_testbench.ino, main.cpp]
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2026-08-31 Replace TestBench04 with alpha01 feeder firmware
    Ports the AS5600 + DRV8833 closed-loop wheel-position control onto pins
    taken directly from the real Feeder board schematic (V0.2a/b) instead of
    ad-hoc bench wiring, and adds RS485 transport on USART0 with RE/DE
    direction control. Debug output moves to Serial1 (USART1) so it no
    longer shares the live bus.
    Also adds a minimal placeholder frame (not Modbus) to validate
    addressing/transport/CRC on real silicon, persistent EEPROM-backed
    feeder addressing (sticky 1-247 address + a reserved parking address for
    never-assigned feeders, relying on the existing one-at-a-time
    programming bus to avoid collisions), and a Modbus RTU feasibility
    write-up in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
    [drv8833_as5600_testbench.ino, main.cpp, pins_config.h]
2026-08-31 Redesign alpha01 addressing: disposable bus address + persistent component config
    Drops the EEPROM-persistent-address/parking-address scheme, which relied
    on a dedicated one-at-a-time programming bus that's no longer part of the
    project (feeders now program over the same shared rail they run on).
    Bus address is now RAM-only and re-earned every boot via a jittered
    CMD_DISCOVER/CMD_DISCOVER_HERE/CMD_ASSIGN_ADDR exchange, so it's cheap to
    throw away and redo on every reinsertion instead of needing exclusive bus
    access to assign collision-free.
    What actually persists in EEPROM is the loaded-component config
    (componentId matching openPnP/parts.xml, tapeZeroRaw, feedHalfTeeth),
    sticky across pow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
    [main.cpp]
2026-08-31 Add tape-zero calibration and distance-based motion helpers to alpha01
    Adds a "zero" reference position per loaded component: ZEROHERE/
    CMD_ZERO_HERE captures the current AS5600 position (as a 12-bit count)
    into cfg.tapeZeroRaw once the operator has jogged the wheel so the first
    pocket is aligned.
    Adds mm-based motion helpers so nothing above them needs to know a step
    is 9 degrees: degForMm()/mmForDeg() derive from DEG_PER_MM (sprocket
    holes are fixed 4mm apart per EIA-481, wheel geometry already known from
    the TestBench03/04 bench tests), halfTeethForMm()/setFeedPitchMm() let a
    pitch be set in mm and auto-translate to feedHalfTeeth, and moveByMm()/
    moveToTapeZeroPlusMm()/feedOnePitch() bui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
    [main.cpp]
2026-08-31 Split PICK_OFFSET_MM out as a fixed mechanical constant, not per-reel
    ZEROHERE previously captured one number that conflated two different
    things: which sprocket hole is seated (varies per reel/leader length)
    and the fine mechanical distance from a seated hole to the actual pick
    point (fixed PCB/frame geometry, identical on every feeder of this
    design). That meant redoing a camera fine-tune every time a reel was
    loaded, for a distance that never actually changes.
    Adds PICK_OFFSET_MM as a single hardcoded firmware constant (not
    per-feeder EEPROM data) representing that fixed offset, measured once
    via MOVEMM with a camera on a reference unit. tapeZeroRaw now stores
    only the hole reference; mo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
    [main.cpp]
2026-09-08 alpha01: fix status LED timing/color, add motor B + magnet-detect debug aids
    - Switch onboard SK6812 status LED back to NEO_KHZ800: the part's own
    datasheet (T0H max 0.40us, T1H 0.65-1.00us) matches standard 800kHz
    WS2812 timing, not the 400kHz variant tried mid-bringup. The real bug
    causing the stuck-white LED was the CKDIV8 fuse never being cleared,
    leaving the chip at an effective 1MHz instead of the intended 8MHz.
    - Add upload_flags = -B 8 and lib_deps for Adafruit NeoPixel.
    - Add PIN_EXT_LED (D13/PB5) on/off control via CMD_SET_EXT_LED and the
    debug "LED ON"/"LED OFF" commands.
    - Alpha hardware bring-up only, not final behavior: SW1/SW2 now jog
    motor A/B open-loop (no AS5600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
    [main.cpp, pins_config.h]
2026-09-09 Add alpha02 (closed-loop bring-up w/ magnet) and RS485 echo mode to alpha01
    alpha02 forks alpha01 for the next bring-up stage now that a magnet is
    mounted on real hardware: SW1 goes back to closed-loop tooth-stepping via
    commandMoveTo()/moveToAngle() (stall/timeout/fault handling exercised for
    real, not bypassed), while SW2 stays an open-loop motor B jog since that
    motor has no encoder on this design to begin with. Motor direction is now
    a runtime flag per motor (invertMotorA/invertMotorB, defaulting to false)
    instead of the old compile-time INVERT_DIRECTION constant, flippable from
    the debug port (INVERTA/INVERTB ON/OFF) or the bus (CMD_SET_INVERT_DIR)
    without reflashing, since lead polarit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
    [main.cpp, pins_config.h]
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2026-09-09 alpha02: full RS485 packet support + tape width as hardware identity
    Now that alpha02 is headed for a live PnP test rather than staying on the
    bench, upgrades the placeholder command set into what a real host
    actually needs:
    - CMD_GET_STATUS: live telemetry (raw angle, AS5600 status byte, DRV8833
    fault state, last move error code) without needing a move to be in
    progress.
    - CMD_STOP: remote e-stop, brakes both motors immediately.
    - CMD_IDENTIFY: blink the status LED (white, distinct from the normal
    green/red magnet-status color) so an operator can find which physical
    feeder holds a given bus address.
    - Proper ERR_* codes (fault/magnet-lost/stall/timeout/bad-param/not-ready)
    return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
    [main.cpp]
2026-09-09 Add alpha03 - the beta1 codebase: dedicated LED2 + AT24CS02 support
    Forked from alpha02, but the first firmware written ahead of a hardware
    revision rather than following one - beta1's schematic should be built
    to match this, not the other way around.
    Two changes, neither of which exists on any V0.2a board built so far:
    - PIN_EXT_LED (D13/PB5, plain on/off, shared the ISP header's SCK line)
    is retired, replaced by a dedicated second SK6812 pixel on its own pin
    (PIN_LED2_DATA, A3/PC3 - unused since the AS5600 switch retired the old
    optical-interrupter signals there). Same job (CMD_SET_EXT_LED / LED
    ON-OFF, lit only on request, never auto-updated), now color-capable via
    a firmware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
    [main.cpp, pins_config.h]
2026-09-09 alpha03: revert LED2 to a standard LED, direct-drive on A3/PC3
    20mA is well within the ATmega328PB's 40mA absolute-maximum DC current
    per I/O pin (Microchip datasheet) - the conventional design point for
    driving an LED straight off an AVR pin, same current class as e.g. the
    Arduino Uno's own onboard LED. No transistor needed.
    Reverts the dedicated SK6812 pixel added earlier for this pin back to a
    plain on/off LED (PIN_EXT_LED, same naming/command interface as alpha01/
    02's CMD_SET_EXT_LED / LED ON-OFF), just moved from D13/PB5 (shared the
    ISP header's SCK line) to A3/PC3 (its own pin, no ISP conflict) to keep
    the benefit of getting off that pin without the complexity of an
    addressable LED.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
    [main.cpp, pins_config.h]
2026-09-18 Add beta1: I_MON/5V_READY/485_RELAY pins, OUT1/OUT2 motor swap
    Forked from alpha03. New pins, none on any board built so far:
    - PIN_I_MON (A6/PE2): analog, voltage proportional to 12V rail current
    draw. Exposed raw (IMON debug command, CMD_STATUS_INFO) - no amps
    conversion yet, needs the current-sense IC's gain/shunt spec once
    chosen.
    - PIN_5V_READY (A7/PE3) + PIN_485_RELAY (D13/PB5, reusing the pin
    PIN_EXT_LED vacated in alpha03): a 1k/1k divider gates a MOSFET-driven
    relay that physically connects/disconnects this feeder's RS485 lines
    from the shared bus, engaging only once the rail has read stable for
    500ms. Caught a real gotcha implementing this: the divider taps the
    sam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
    [main.cpp, pins_config.h]
2026-09-18 beta1: switch 5V rail divider from 1k/1k to 4.7k/1k
    The internal-1.1V-reference fix for the AVCC self-reference problem
    introduced a new issue: a 1k/1k divider puts ~2.5V at the pin, which
    clips the ADC reading to max once the rail crosses ~2.2V - well short
    of a healthy 5V, unable to distinguish "still ramping" from "arrived."
    Switched to 4.7k (rail side) / 1k (GND side): ~0.88V at 5V nominal,
    ~816/1023 counts against the 1.1V reference, clipping only above
    ~6.27V - comfortably clear of a 5V rail's tolerance while using ~80%
    of the ADC's range, roughly 2x the resolution of a 10k/1k alternative.
    No firmware logic changed - waitFor5vStableAndEngageRelay() compares
    consecutive raw ADC readin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
    [main.cpp, pins_config.h]
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2026-09-18 beta1: hand-calibratable IMON/5V_READY + rough 5V-rail current estimate
    Real resistor/RIMON tolerances mean the datasheet/calculator math is
    only a starting point, not the actual per-board scale - add a bench
    calibration workflow so it can be dialed in against a real
    ammeter/multimeter once a bed-of-nails test jig exists.
    AnalogCalibration stores one (raw ADC, real-world value) point per
    signal - imonCalRaw/imonCalMa, v5vCalRaw/v5vCalMv - persisted in the
    ATmega's internal EEPROM, independent of FeederConfig/FeederHardwareInfo
    (a component change or RESETCFG must never touch it). Falls back to the
    factory-calculated defaults (4.07V/200mA for IMON, 816/1023 @ 5000mV
    for 5V_READY) until calib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
    [main.cpp]
2026-09-18 beta1: fix i5v estimate rationale - VMOT is on 5V, not 12V
    Wrong assumption in the estimateI5vMilliamps() comments/docs: claimed
    the motor driver draws straight off 12V, bypassing the 5V regulator,
    and used that to explain why the estimate reads high when a motor
    runs. Actually backwards - DRV8833's VMOT is tied to the 5V rail
    (through a ferrite bead for noise isolation), not 12V, so the motor
    IS a 5V-rail load, not something bypassing it. There's no significant
    12V-only load on this board to throw the power balance off; the only
    real error source is buck conversion efficiency (<100%), which makes
    the true 5V-rail current somewhat LOWER than the estimate, not higher.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
    [main.cpp]
2026-09-22 beta1: stagger + gate boot-time homing on magnet placement
    calibrateZero() (the DRV8833 still/breakaway duty characterization) was
    the only motor movement this firmware does unprompted, and alpha02/03
    ran it synchronously from setup() on every boot. On a real bus with
    multiple feeders sharing a 12V rail through individual TPS26600 eFuses,
    that's a problem twice over: a feeder that was just hot-plugged stacks
    a motor breakaway-current spike on top of its own insertion inrush, and
    several feeders powered up together would all hit that spike at once.
    Deferred to a new checkHoming() gate polled from loop() instead of
    setup(), so it doesn't block the debug port or RS485 bus while it
    waits:
    - HO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
    [main.cpp]
2026-09-22 beta1: swap DRV8833 channel A/B pins - feed/peel motors were crossed
    First real beta1 bench test: commanding "motor A" (the closed-loop
    feed/sprocket logic) moved the peel motor instead of the feed motor.
    Different bug from invertMotorA's within-channel direction swap - this
    is which DRV8833 channel drives which physical motor connector at all,
    found to be crossed relative to what alpha01-03's pin numbers assumed.
    Fixed by swapping PIN_AIN1/PIN_AIN2 with PIN_BIN1/PIN_BIN2 in
    pins_config.h (both include/ and src/ copies) rather than touching any
    logic in main.cpp: driveMotorA()/moveToAngle() etc. are still "the
    closed-loop feed motor," driveMotorB() still "the open-loop peel
    motor," just bac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
    [main.cpp, pins_config.h]
2026-09-22 beta1: fix compile error + calibration-corruption bug from review
    Two real bugs found on a full read-through before real hardware testing:
    1. handleFrame()'s CMD_GET_STATUS case uses readIMonRaw() and
    relayEngaged, both defined ~300 lines later in the file with no
    forward declaration. Unlike a .ino sketch, PlatformIO doesn't
    auto-prototype a .cpp - this file already hand-declares readAngleDeg()
    etc. for exactly this reason, but this pair was missed when
    CMD_STATUS_INFO grew to 8 bytes earlier in the session. Wouldn't have
    compiled. Added the missing forward declarations.
    2. The CALI <mA> debug command wrote analogCal.imonCalRaw = readIMonRaw()
    before checking whether t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
    [main.cpp]
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2026-09-22 beta1: fix false heartbeat warning w/o magnet, add SELFTEST command
    Three fixes/additions from bench testing feedback:
    1. The "WARN: wheel moved between heartbeats" check compared
    readAngleDeg() readings 3s apart regardless of magnet presence.
    Without a magnet, the AS5600 still ACKs over I2C but returns noise
    with nothing to lock onto, so it was firing constantly and
    meaninglessly whenever no magnet was mounted. Now skipped entirely
    while !magnetDetected(), and the baseline is dropped in that state so
    a magnet reappearing starts a fresh comparison instead of comparing
    a real angle against stale noise.
    2. Added a SELFTEST debug command that re-runs runDebugSelfTest() on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
    [main.cpp]
2026-09-22 beta1: add relay button-test mode (hold SW1/SW2 at boot)
    Simpler, more useful version of relay bench testing than
    runDebugSelfTest()'s fixed 800ms x2 auto-cycle: hold either SW1 or SW2
    while powering up to enter a dedicated mode. RGB goes fixed blue to
    confirm entry, then red (relay off) once the boot press is released and
    debounced - from there every SW1/SW2 press toggles the relay and the
    RGB (green=on/red=off) for as long as needed, instead of a fixed
    timed sequence. Blocks forever once entered; power-cycle without
    holding a button for a normal boot. No-op (returns immediately) if
    neither button is held when checked.
    Required moving Serial1.begin(DEBUG_BAUD) to the very top of setup()
    (w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
    [main.cpp]
2026-09-22 beta1: confirm A6/A7=PE2/PE3 mapping against real MiniCore toolchain
    User reported zero voltage movement on PIN_5V_READY (A7/PE3) and asked
    to quadruple-check the pin usage. Found MiniCore's actual installed
    package on this machine
    (~/.platformio/packages/framework-arduino-avr-minicore/variants/pb-variant/pins_arduino.h)
    and checked every step of the chain instead of assuming:
    - PIN_A7 = 26, PIN_PE3 = 26 - A7 really is PE3 on this toolchain.
    - analogPinToChannel(26) = 7 - analogRead(A7) resolves to ADC7.
    - ADMUX gets (pin & 0x07) = 7 with MUX5 correctly 0 - right channel.
    - Arduino.h's ATmega328PB branch: INTERNAL/INTERNAL1V1 = 3
    (REFS1:REFS0=11), the 1.1V bandgap - matches what firmware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
    [pins_config.h]
2026-09-22 beta1: fix PIN_5V_READY/PIN_485_RELAY - were assigned backwards
    User correction: PE3/A7 is the relay drive (digital OUTPUT, HIGH=active/
    connected, LOW=disconnected, pulled low by an external resistor), not
    the 5V-rail-sense ADC input as this codebase had assumed throughout.
    PIN_5V_READY is actually on A2/PC2 (ADC2, one of the classic ADC0-5
    pins). PIN_I_MON (A6/PE2) was already correct and is unchanged.
    This explains the "zero voltage movement" report from the previous
    turn - I was diagnosing the wrong signal entirely (checked the ADC
    channel/reference chain for A7 as an analog input, when the real
    problem was that firmware never drove PE3 as a relay output at all,
    since PIN_485_RELAY poin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
    [main.cpp, pins_config.h]
2026-09-22 beta1: temporary SW1/SW2 open-loop jog test (wiring check, no magnet needed)
    One-time bench check before forking to v0.01a: both buttons now drive
    their motor open-loop, bypassing moveToAngle()'s magnet check entirely,
    so this works with no magnet mounted. Each press toggles direction
    (forward, then backward, ...) - click -> forward -> backward. SW1 tests
    motor A, SW2 tests motor B, independently.
    Replaces SW1's normal closed-loop tooth-step behavior for this check -
    not meant to carry into v0.01a; that fork keeps the real button
    behavior (SW1 closed-loop, magnet-gated; SW2 always-forward jog).
    [main.cpp]
2026-09-22 Add v0.01a: first MAJOR-version release, forked from beta1
    The stepping stone going forward, not another bench-iteration
    alpha/beta. Forked from beta1 at commit ef0b24f (the PIN_5V_READY/
    PIN_485_RELAY correction), deliberately NOT including the temporary
    SW1/SW2 open-loop jog test added to beta1 afterward for a one-off
    wiring check - that stays beta1-only.
    Only functional difference from that beta1 state: the bench-only
    auto-run test aids are disabled by default -
    - runDebugSelfTest() (relay x2/ext LED toggle + IMON/5V readout on
    every boot) and runRelayButtonTest() (hold SW1/SW2 at power-up to
    hijack the relay) are commented out of their setup() call sites, not
    deleted - both funct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
    [main.cpp, pins_config.h]
2026-09-22 v0.01a: disable startup RGB splash too, replace with boot-status yellow
    Follow-up to the test-aid disabling: showStartupLedSequence()'s
    red/green/blue splash still ran unconditionally at boot even with
    runDebugSelfTest()/runRelayButtonTest() commented out - not a relay
    toggle (that part was already handled), but the same category of
    "boot behavior that doesn't reflect anything real" this release is
    meant to drop.
    Replaced with solid yellow held from early in setup() (booting, not
    ready yet) until loop()'s first iteration overwrites it with the real
    magnet-detect green/red. RGB now only ever shows "not ready" or true
    current status - nothing decorative. Relay gating itself untouched;
    the LED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
    [main.cpp]
2026-09-26 v0.01a: status LED, feed fixes, fast feed, peel control, flash 97%->70%
    - Feed direction fixed (confirmed on hardware): invertMotorA now flips
    motor drive AND AS5600 angle together so the loop stays consistent;
    default true = tape feeds forward on the real board.
    - Tooth seating always approaches backwards (snapToToothBackward()),
    run after homing and via SNAP.
    - SW1 hold >= 700ms = fast feed, one full sprocket turn (also FASTFEED).
    - SW2 runs the peel motor while held (tape tensioning), plus PEEL <ms>
    debug command and CMD_PEEL (0x34) bus command. TODO noted: final roles
    are SW1 = feed, SW2 = unfeed.
    - Status RGB: yellow booting, blue ready, red error, purple moving.
    - DRV8833 sle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
    [main.cpp]
2026-10-03 Add PC-side RS485 command sender tool for protocol bench testing
    A Python/pyserial script (Feeders/Feeder board/SW/tools/rs485_sender.py)
    that opens a USB-RS485 adapter on a COM port and drives the feeder
    protocol directly - frame building, CRC8, and response decoding all
    implemented straight from PROTOCOL.md/v0.01a's main.cpp, cross-checked
    against an independently-written CRC8 reference over 2000 random inputs.
    Interactive REPL with a named command per protocol command (ping, scan,
    assign, getcomponent/setcomponent, setfeedconfig, resetconfig, zerohere,
    setpitch, feednext, setled, setinvert, gethwinfo/sethwinfo, getstatus,
    stop, identify, getserial, peel) plus a raw <addr> <cmd> [hexbytes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
    [rs485_sender.py]
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2026-10-04 v0.01a: stop re-toggling ADC reference every sample during 5V stability check
    waitFor5vStableAndEngageRelay() called readAdcInternalRef() on every
    20ms poll, which switched AVCC->INTERNAL->(settle)->read->back to AVCC
    on EVERY sample, repeated up to 250 times across the 5s timeout. That
    reference-switching itself is a likely source of sample-to-sample
    jitter on top of whatever the rail is actually doing, which combined
    with the tight +/-8-count (~49mV) plateau window could make a
    perfectly healthy rail look like it never stabilizes.
    Now switches to INTERNAL once at the top of the function and back to
    DEFAULT once at the end (success or timeout), holding the reference
    steady for the whole po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
    [main.cpp]
2026-10-04 v0.01a: motor soft-start ramp + ignore buttons held through boot
    Real-hardware symptom: the 12V eFuse trips on motor commands, not at
    boot. Two independent contributors, both fixed here.
    1. No motor command ramped duty at all - driveMotorA()/driveMotorB()
    stepped straight from stopped to the target duty in one analogWrite().
    A motor at a dead stop has no back-EMF yet, so that's close to full
    voltage across the winding resistance - the locked-rotor/breakaway
    current regime, briefly well above running current. VMOT sits on the
    5V rail, so that spike is drawn from the buck's output and reflected
    back to its 12V input (roughly scaled by the step-down ratio) -
    exactly what t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
    [main.cpp]
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

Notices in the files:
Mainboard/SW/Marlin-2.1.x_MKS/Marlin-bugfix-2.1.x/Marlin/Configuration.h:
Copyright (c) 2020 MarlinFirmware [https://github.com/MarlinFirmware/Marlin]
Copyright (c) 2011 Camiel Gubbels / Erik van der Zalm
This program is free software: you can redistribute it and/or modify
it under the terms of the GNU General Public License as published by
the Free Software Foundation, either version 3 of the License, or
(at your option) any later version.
